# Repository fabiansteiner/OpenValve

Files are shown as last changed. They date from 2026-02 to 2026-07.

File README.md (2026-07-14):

<div align="center">

# OpenValve

<a href="https://open-valve.com/">Get OpenValve</a> | <a href="documents/Construction.md">Build OpenValve</a> | <a href="https://docs.open-valve.com">Documentation</a> | <a href="https://discord.gg/JMEDK97xuT">Join Discord</a>

</div>

## Introduction

OpenValve is an **open-source, 3D-printable irrigation controller**. It waters plants based on **actual soil moisture**, works with **gravity-fed systems**, and runs on a **9V block battery for about 3 months**.

OpenValve First Impressions

OpenValve was built for irrigation. But underneath the soil moisture sensor and irrigation firmware is an open-source pinch valve that you can build other things around.

> [!NOTE]
> **Built for irrigation. Open to other ideas.**
> Add your own sensor, write your own firmware, or connect OpenValve to another system. [Explore OpenValve as a valve platform →](documents/OV-as-platform.md)

## Applications
OpenValve was designed for **balconies, garden beds, small greenhouses, and other small-to-medium irrigation setups**. It has been deployed in multiple real-world locations. Both gravity-fed and faucet-fed (`≤ 4 bar`) setups were successfully tested over full summer seasons.

OpenValve in multiple locations

## ✨ Key Features

### 🚰 3D-Printable Pinch Valve

- bistable (no power needed to hold the open/closed position)
- reliably actuates **down to 0 bar**, making it **perfect for gravity-fed setups**
- requires **no minimum flow**
- tolerates **imperfect or particle-rich water**  
- **8 mm inner flow path** (Cv ≈ 2)  
- Max. pressure: **4 bar** (60 psi)  

Open Valve First Impressions

### 🌧️ Sensor-Based Irrigation

OpenValve does not water on a fixed timer. Instead, it uses a **soil moisture sensor** to decide when watering is needed.

#### How it works:

1. OpenValve regularly measures the soil moisture.
2. If the soil is drier than the threshold you set, the valve opens.
3. Water flows until the sensor detects that moisture is increasing.
4. The valve then either closes immedetiately or stays open for longer, based on the extra watering time you set.
5. OpenValve stops watering and returns to the regular soil moisture measurement.

This allows the watering frequency to adapt to the actual conditions around the plant instead of following a fixed schedule:

When the soil dries out faster, for example during hot weather or periods of increased plant demand, OpenValve waters more often. When the soil stays moist for longer, for example during cooler weather, after rainfall, or after a previous watering cycle, OpenValve waters less often.

For a more detailed explanation of the watering logic, see the ["How OpenValve works" section in the documentation.](https://docs.open-valve.com/category/how-openvalve-works) 

How OpenValve waters

### 🔗 Standard Hose & Pipe Connections

OpenValve has a standard **½″ male BSPP thread on both ends**. This thread size is common in irrigation and plumbing systems in Europe, the UK, Australia, and many other regions.

Any fitting, adapter, or component with a compatible **½″ female BSPP thread** can be connected directly to OpenValve, for example:

* compression fittings
* hose connectors
* thread adapters, such as ½″ to ¾″
* quick-connect fittings
* adapters for different hose sizes

This makes OpenValve flexible enough for setups ranging from a small balcony drip line to a greenhouse irrigation system.

For more details about installing OpenValve, see the [installation section in the documentation](https://docs.open-valve.com/installation/overview).

### 🛠️ Fully Repairable & Modifiable

OpenValve is designed to be repaired, modified, and reused.

* the 3D-printed parts can be reprinted or modified
* the silicone hose (pinch valve sleeve) can be replaced when it wears out
* the firmware can be changed for different behaviours
* the hardware and firmware allow easy integration of different sensors
* the valve can alternatively be powered from an external 5 V, 1 A supply

OpenValve was designed for irrigation, but can also be used for other projects. [Explore OpenValve as a valve platform →](documents/OV-as-platform.md)

## 💡 User Interface

OpenValve’s user interface (UI) is intentionally minimal:

- **1 button**
- **2 LEDs**: one blue LED and one bi-color LED that can show green, red, or orange

Because the device is designed to run autonomously, the UI focuses on simple, essential interactions:

- **Short and long button presses** for menu navigation and configuration  
- **LED patterns** to indicate status, watering activity, sensor readings, and possible errors

To make this easy to understand, every UI state is documented and can be explored interactively:

👉 **Interactive Manual:**  https://ui.open-valve.com/

This web-based “digital twin” mimics the behaviour of the real device - showing the same LED patterns and button interactions, along with explanations for each state.  

For a complete explanation of the button actions, LED blink patterns, and UI states, see the [User Interface documentation](https://docs.open-valve.com/category/user-interface).

## 🤝 Contributing

Contributions are welcome!  
If you’d like to help improve the firmware, CAD files, documentation, or electronics, feel free to open an issue or submit a pull request.

You can also [join the project Discord](https://discord.gg/JMEDK97xuT) to discuss ideas, ask questions, or share feedback.

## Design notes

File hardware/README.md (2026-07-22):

# Bill of Materials (BOM)

In addition to the [PCB](./pcb) and [3D-printed parts](./3D-models), the following components are required to build one OpenValve.

> [!NOTE]
> The product links below are examples, not endorsements. Availability may change, and equivalent parts can be used if their dimensions, materials, and specifications match.

## Enclosure, sealing, and ventilation

| Component | Quantity | Example product |
| --- | ---: | --- |
| M12 cable gland | 1 | [TE Connectivity 1SNG601011R0000 — DigiKey](https://www.digikey.at/en/products/detail/te-connectivity-entrelec/1SNG601011R0000/19203103) |
| Gasket for M12 cable gland | 1 | [TE Connectivity ENBR-WG-M12-BL-A — DigiKey](https://www.digikey.at/en/products/detail/te-connectivity-entrelec/ENBR-WG-M12-BL-A/16686555) |
| Gasket for fitting | 2 | [EPDM flat gasket — PVC-Welt](https://www.pvc-welt.de/EPDM-Flachdichtung-Shore-55-fuer-Aussengewinde-und-Tankdurchfuehrung) |
| Silica gel bag, 10 g | 1 | [Example — Amazon](https://www.amazon.de/dp/B0CTGPC5VB) |
| M12 hydrophobic vent | 1 | [Amphenol LTW VENT-PS1NGY-N8001 — DigiKey](https://www.digikey.at/en/products/detail/amphenol-ltw/VENT-PS1NGY-N8001/7898282) |
| O-ring, 58 mm OD × 2 mm, NBR 70 | 1 | [Example — AliExpress](https://de.aliexpress.com/item/4000867504808.html) |
| O-ring, 30 mm ID × 1.5 mm, NBR 70 | 1 | [Example — Persicaner](https://www.persicaner.at/produkt/nbr-70-o-ring-30-00x1-50o/) |

## Fasteners and mechanical hardware

| Component | Quantity | Example product |
| --- | ---: | --- |
| M3 × 6 mm button-head socket screw, A2 stainless steel | 4 | [ISO 7380-1 screw — Schraubenking](https://www.schraubenking.at/M3-x-6mm-Linsenflachkopfschraube-ISK-ISO7380-1-Edelstahl-A2-P004587) |
| M3 × 10 mm button-head socket screw, A2 stainless steel | 4 | [ISO 7380-1 screw — Schraubenking](https://www.schraubenking.at/M3-x-10mm-Linsenflachkopfschraube-ISK-ISO7380-1-Edelstahl-A2-P002586) |
| M4 × 10 mm button-head socket screw, A2 stainless steel | 3 | [ISO 7380-1 screw — Schraubenking](https://www.schraubenking.at/M4-x-10mm-Linsenflachkopfschraube-ISK-ISO7380-1-Edelstahl-A2-P002759) |
| M4 × 8 mm button-head socket screw, A2 stainless steel | 1 | [ISO 7380-1 screw — Schraubenking](https://www.schraubenking.at/M4-x-8mm-Linsenflachkopfschraube-ISK-ISO7380-1-Edelstahl-A2-P004441) |
| M4 thin square nut, DIN 562, A2 stainless steel | 1 | [Square nut — Schraubenking](https://www.schraubenking.at/M4-Vierkantmuttern-niedrig-DIN562-Edelstahl-A2-P003727) |
| M4 × 6.35 mm threaded insert | 3 | [Threaded insert set — 3DJake](https://www.3djake.at/3djake/gewindeeinsaetze-50er-set?sai=9420) |
| M3 × 5.7 mm threaded insert | 2 | [Threaded insert set — 3DJake](https://www.3djake.at/3djake/gewindeeinsaetze-50er-set?sai=9420) |
| 3 mm × 10 mm cylindrical pin, A1 / 1.4305 stainless steel | 2 | [DIN 7 cylindrical pin — Schraubenhimmel](https://www.schraubenhimmel.de/schrauben/ohne-kopf/zylinderstifte/ungehaertete-ausfuehrung/33260/din-7-edelstahl-a1-1.4305-3x10-zylinderstift-toleranz-m6) |

## Electronics and actuation

| Component | Quantity | Example product |
| --- | ---: | --- |
| 9 V battery clip cable, 15 cm | 1 | [Example — AliExpress](https://de.aliexpress.com/item/1005009963920324.html) |
| Soil moisture sensor | 1 | [SoilWatch 10 — Pino-Tech](https://pino-tech.eu/product/soilwatch-10/) |
| JGA25-370 DC gear motor, 6 V, 10 RPM | 1 | [Example — AliExpress](https://de.aliexpress.com/item/32987942205.html) |

## Valve tubing and assembly materials

| Component | Quantity | Example product |
| --- | ---: | --- |
| Silicone hose, 94 mm length, 60 Shore A | 1 | [8 × 12 mm silicone hose — Persicaner](https://www.persicaner.at/produkt/silikonschlauch-8x12o-transluzent) |
| Silicone adhesive | 1 | [Example — Amazon](https://amzn.eu/d/0cmCepki) |
| Silicone grease | 1 | [Example — Amazon](https://www.amazon.de/dp/B07BFHRT48) |

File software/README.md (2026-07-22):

# 🧠 Firmware

The firmware can be opened, modified, and built using [Microchip Studio](https://www.microchip.com/en-us/tools-resources/develop/microchip-studio).

## 🔌 Flashing Firmware

### UPDI Programmers

OpenValve uses **UPDI (Unified Program and Debug Interface)**.  
To flash firmware, you’ll need a **UPDI programmer**.

You have two options:

#### 1. Make your own programmer:

If you have an **Arudino Uno or Arduino Nano** or any other MCU Board based on the ATMEGA328P lying around you can quite easily use those as a UPDI programmer. The only additional hardware components you need are:
Any capacitor of 1uF or more, and a few jumper wires. 

If you have those components, use the following video as a reference to prepare your programmer:

👉 https://www.youtube.com/watch?v=AL9vK_xMt4E

#### 2. Buy a ready-made programmer
The **NanoUPDI** for example is an inexpensive ready-to-use option:

- GitHub: https://github.com/umbertoragone/nanoupdi  
- Available on:
  - https://lectronz.com/  
  - https://www.tindie.com/  

There are also many other inexpensive UPDI programmers available. When buying one make sure there is the option to set the power output of the programmer to 3.3V.

### How to flash new firmware

The easiest way to flash new firmware without installing Microchip Studio is by using [AVRDUDESS](https://github.com/ZakKemble/AVRDUDESS):

Get the newest firmware from the latest release. Connect OpenValve with your programmer using jumper cables. Make sure the programmers **output power Pin is 3.3V, not 5V**. Then connect the programmer with your PC via USB. 

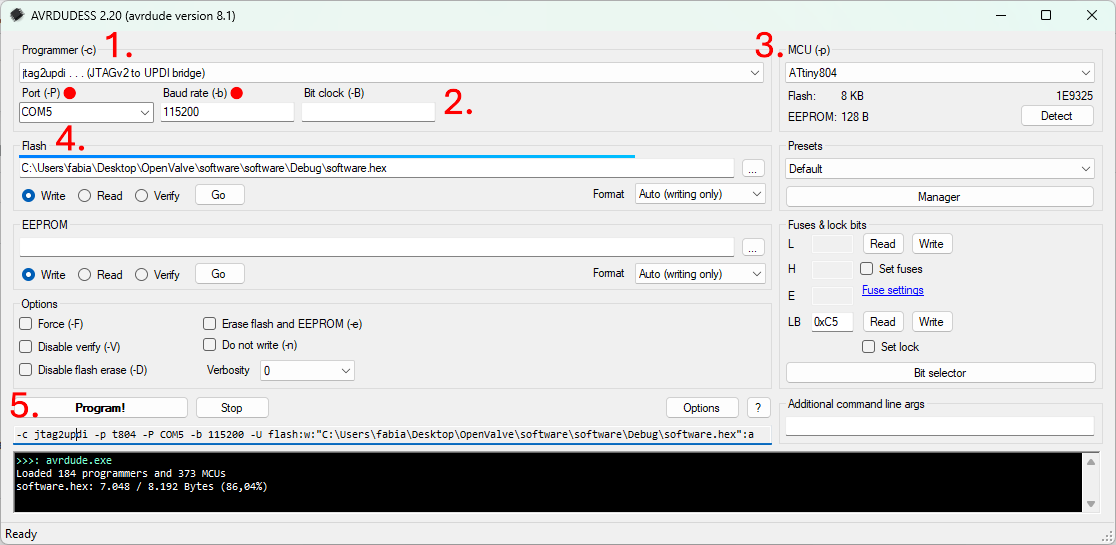
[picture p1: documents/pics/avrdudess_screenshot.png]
avrdudess_settings


Open AVRDUDESS and:

1. Choose the right programmer. jtag2updi for Arduino Uno/Nano based programmer, or SerialUPDI for the NanoUPDI programmer.
2. Choose correct PORT (USB port of your programmer) and Baudrate: 115200
3. Choose correct MCU: ATtiny804
4. Choose firmware binary that should be flashed. (.hex file from the release)
5. Hit Program! 

### ⚠️ Important Warning

The DC motor control logic located in `software/valve.c` is **highly tuned and timing-sensitive**.  
Modifying it without fully understanding the mechanism will **very likely destroy the motor gearbox**.

Proceed with extreme caution when changing anything related to:

- motor control timing  
- stall detection  
- open/close cycle control 
- interrupt behaviour

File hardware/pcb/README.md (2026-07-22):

# 🛠️ Electronics

The PCB was designed using KiCad. OpenValve is based on the ATTINY804 microcontroller.

Schematic, PCB layout and BOM are all open.

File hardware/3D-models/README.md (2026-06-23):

# 🧵 3D Models

All custom plastic parts of OpenValve are **designed and optimized for 3D printing**. No generated support material is required.

This document contains information about the parts and how to produce them yourself.

> [!WARNING]
> Functionality and long-term reliability can only be achieved when all components are printed using the specified materials and slicer parameters.

## ASA Parts

### Tested Filaments

* Fiberlogy ASA
* Prusament ASA

> [!CAUTION]
> Do not use dark filament colors if you intend to use OpenValve outdoors in direct sunlight. Dark colors heat up to higher temperatures under the same conditions and may deform over time.

### Global Slicer Settings

Use these settings for **all ASA parts**, unless stated otherwise in the part-specific section.

| Setting | Value |
| --- | --- |
| Nozzle size | 0.4 mm |
| Layer height | 0.2 mm |
| Perimeters | 4 |
| Infill | 100% |
| Infill pattern | Rectilinear |
| Supports | None |
| Fuzzy skin thickness | 0.2 mm — paint-on only |
| Fuzzy skin point distance | 0.6 mm — paint-on only |

### Print-Yourself ASA Parts

Some ASA parts can either be purchased with the assembly kit or printed by the user:

* `Housing_Up`
* `Housing_Down`
* `Nut_scaled` ×2
* `Guide`
* `MotorMount`
* `Slider`

Ready-to-print profiles for these parts are available on [Printables](https://www.printables.com/model/1564060-openvalve-missing-parts) and [MakerWorld](https://makerworld.com/de/models/2277535-openvalve-missing-parts#profileId-2483396).

Detailed print instructions for these parts can also be found there.

### ASA Parts Included in the Assembly Kit

The following ASA parts are included in the assembly kit by default. They are more difficult to produce reliably, but the settings below are provided for users who still want to print them themselves.

### Part-Specific Slicer Settings

#### Fitting (2 pieces)

The fittings require post-processing by impregnating them with **Dichtol AM Hydro** to handle water pressure. For this reason, they are included in the assembly kit.

| Setting | Value |
| --- | --- |
| Scarf joint placement | Everywhere |
| Enable ironing | Yes |
| Ironing type | Topmost surface only |

#### Battery Lid

The battery lid has an embedded QR code that needs 2 different ASA filaments, a smooth print sheet and very specific slicer settings if printed on a single-extruder system. For that reason it is included in the assembly kit by default.

With a multi-material system, the battery lid should be easy to print. 

If your printer does not have a multi-material system, a dual-extruder system can be simulated to allow a mid-layer material change by tweaking a few slicer settings (PrusaSlicer):

| Path | Setting |
| --- | --- |
| `Printers → General → Extruders` | `2` |
| `Printers → General → Custom G-code → Tool change G-code` | `M600`  |
| `Print Settings → Multiple Extruders → Wipe Tower` | Off |

##### Steps

1. Select two materials (both ASA).

   * Material 1 → QR code (preferably black)
   * Material 2 → rest of the battery lid
2. Assign extruders:

   * Battery lid body → **Material 2**
   * QR code bodies → **Material 1**
3. Slice the model.
4. Inspect the first layer preview.
5. Print if correct

> [!NOTE]
> G-code compatibility warnings can be ignored.

## PC Parts

All PC parts are included in the assembly kit by default.

They are included because they must stay within very narrow tolerances and require highly repeatable printing results. They also require special assembly tools and precise post-processing.

In addition, polycarbonate is not a commonly used 3D-printing material and may not be readily available to every user.

### Tested Filament

* Prusament PC Blend

### Global Slicer Settings

Use these settings for **all PC parts**, unless stated otherwise in the part-specific section.

| Setting | Value |
| --- | --- |
| Layer height | 0.15 mm |
| Perimeters | 4 |
| Infill | 100% |
| Infill pattern | Rectilinear |
| Cooling | Disable the fan for the first layer only |

### Part-Specific Slicer Settings

#### Link2 (2 pieces)

#### Shell (2 pieces)

## Other Parts

### Button

**Tested filament**

* Recreus Filaflex SEBS Black

#### Part-Specific Slicer Settings

| Setting | Value |
| --- | --- |
| Nozzle temperature | 260 °C |
| Layer height | 0.2 mm |
| Perimeters | 4 |
| Infill | 100% |
| Infill pattern | Rectilinear |

### Knob (2 pieces)

**Tested filament**

* Fiberlogy Easy PET-G Pure Transparent

#### Part-Specific Slicer Settings

| Setting | Value  |
| --- | --- |
| Layer height | 0.2 mm |
| Perimeters | 5 |

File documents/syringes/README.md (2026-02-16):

# Syringes

### Silicone Glue

The silicone glue syringe is filled with [Tec7 Rock](https://tec7.com/en-BE/products/mount-seal/rock). Technical and Safety Datasheet can be found on the website. A copy of the safety datasheet is located in the["DS"](DS) folder.

### Silicone Grease
The silicone grease syringe is filled with [weicon silicone grease](https://www.weicon.de/en/silicone-grease-food-safe-lubricating-grease/10050566). Technical and Safety Datasheet can be found on the website. A copy of the safety datasheet is located in the["DS"](DS) folder.

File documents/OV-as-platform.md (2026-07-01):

# OpenValve Beyond Irrigation

OpenValve was originally designed for irrigation. The soil moisture sensor and the firmware turn it into an irrigation controller.

Take those irrigation-specific parts away, and you are left with an **open-source pinch valve**. From there, the project is yours to shape: add your own sensor, write your own firmware, or connect it to another system and use just as a valve.

> [!NOTE]
> **OpenValve comes with one finished application.** What you build around the valve is up to you.

At its core, OpenValve is a bistable pinch valve. It switches quickly, only needs power while moving, and has low internal flow resistance when open. The standard version uses **½-inch BSPP threads** because they are common in irrigation and provide secure connections for pressurised water systems. Not every project needs that, though.

Some projects do not need threaded fittings or higher pressure handling. Instead, they benefit from a clean, uninterrupted flow path. For this, I made an [alternative fitting](../hardware/3D-models/ASA-parts/alternativeParts/) that allow one continuous hose to run straight through OpenValve.

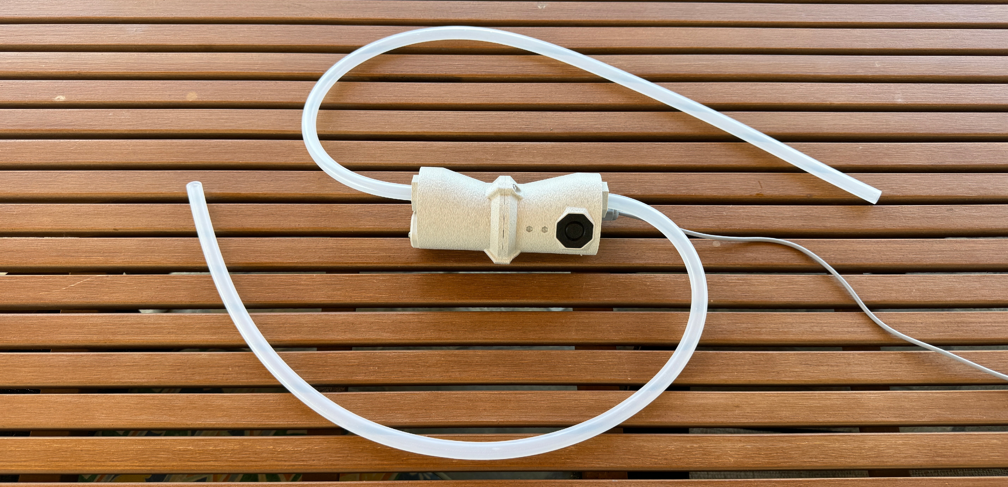
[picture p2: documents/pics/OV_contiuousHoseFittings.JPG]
OpenValve with a continuous hose running through it


The hose can be inserted from the outside without opening the housing. OpenValve pinches the hose from the outside, while the liquid stays inside the hose for the entire path through the valve. The liquid never touches the valve mechanism or housing, similar to a peristaltic pump. The difference is that OpenValve does not pump the liquid. It only opens or closes the hose, while gravity or another external pressure source moves the liquid. Because of that, OpenValve needs only a fraction of the electrical energy that a peristaltic pump would need to move the same amount of liquid, making it generally a good candidate for battery-powered applications.

To give you an idea of where this could become handy, here are a few things I could imagine building with it:

* a gravity-fed cocktail robot, with ingredient bottles above the machine and one valve controlling each ingredient
* a drink dispenser for water, juice, cold brew, syrups, or other liquids
* a small automated refill system for tanks, containers, or reservoirs that refills from an elevated reservoir when a water-level or weight sensor detects that it is low
* a simple timed dosing system for aquarium additives, hydroponic nutrients, fertiliser, or cleaning liquids
* a DIY dispenser for sauces, soap, or other liquids where the product should stay inside a replaceable hose

## Recommended hose for the continuous-hose fittings

OpenValve is designed for hoses with:

* **Inner diameter:** **8 mm**
* **Outer diameter:** **12 mm**
* **Hardness:** **60 Shore A ±10**

The hose hardness is important. A hose that is too hard needs more force to pinch closed, and there is a real risk that it will not fully recover after being pinched. In that case, the hose can stay partially collapsed even when the valve opens, restricting or completely blocking the flow. This is a serious issue and should be considered carefully when choosing a hose.

I tested a range of hose materials and hardnesses. So far, a silicone hose with a **shore hardness of 60A** is the only option that has worked reliably for this design so far.

Because the liquid only touches the inside of the continuous hose, the hose material alone determines which liquids can be transported with it. A certified food-safe silicone hose can for example be used for food-contact applications, as long as the other wetted parts in the final system are also suitable for that use.

## Firmware templates for other projects

The hardware can be used for many different ideas, but the current firmware was built for irrigation. There are no ready-made guides or template firmwares for the examples above yet.

Right now, using OpenValve for a different purpose means adapting the irrigation firmware yourself. That is possible, but it is more work than it should be.

I want to change that by creating small, well-documented template firmwares for practical use cases. These will mostly not be finished and polished firmwares, but simple starting points for projects such as a timed dispenser, a tank refill system or a firmware that just waits for a digital input to open/close the valve.

Have an idea you would actually like to build? [Join the Project Discord](https://discord.gg/JMEDK97xuT) and share it, or write DM. Concrete ideas help me decide which templates and guides to create first.

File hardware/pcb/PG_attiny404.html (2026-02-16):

# C:\Users\fabia\PlantGuardDrive\PCB_Designs\pcb\PG_attiny404.kicad_sch

17.06.2023 08:18:30

Eeschema 7.0.1

Component Count:28

Ref | Qnty | Value | Part | Datasheet | Description | Vendor
C1, C2, C5 | 3 | 1uF | Device:C | ~ | Unpolarized capacitor
C3, C6 | 2 | 100nF | Device:C | ~ | Unpolarized capacitor
C4 | 1 | 10uF | Device:C | ~ | Unpolarized capacitor
J1 | 1 | 0022232041 | dk_Rectangular-Connectors-Headers-Male-Pins:0022232041 | https://www.molex.com/pdm_docs/sd/022232041_sd.pdf | CONN HEADER VERT 4POS 2.54MM
J2, J3, J4, J5, J6, J7, J8 | 7 | Conn_01x01_Male | Connector:Conn_01x01_Male | ~ | Generic connector, single row, 01x01, script generated (kicad-library-utils/schlib/autogen/connector/)
Q1 | 1 | 2N7002 | PG_attiny404-rescue:2N7002-dk_Transistors-FETs-MOSFETs-Single | https://www.onsemi.com/pub/Collateral/NDS7002A-D.PDF
R1, R2 | 2 | 100 Ohm | Device:R | ~ | Resistor
R3 | 1 | 0.5 Ohm | Device:R | ~ | Resistor
R4 | 1 | 665 Ohm | Device:R | ~ | Resistor
R5 | 1 | 200k | Device:R | ~ | Resistor
R6 | 1 | 100k | Device:R | ~ | Resistor
SW1 | 1 | SW_Push | Switch:SW_Push | ~ | Push button switch, generic, two pins
U1 | 1 | ATtiny404-SS | PG_attiny404-rescue:ATtiny404-SS-MCU_Microchip_ATtiny | http://ww1.microchip.com/downloads/en/DeviceDoc/50002687A.pdf
U2 | 1 | AH9246 | project:AH9246 | https://www.diodes.com/assets/Datasheets/AH9246.pdf | Hall Sensor, Package: TO92S
U3 | 1 | XLUGR34M | project:XLUGR34M | https://www.sunledusa.com/products/spec/XLUGR34M.pdf | Red-Green LED with common Cathode
U4 | 1 | ZXCT1009F | Amplifier_Current:ZXCT1009F | https://www.diodes.com/assets/Datasheets/ZXCT1009.pdf | High-Side Current Monitor, SOT-23
U5 | 1 | AP7370-33Y-13 | project:AP7370-33Y-13 | https://www.diodes.com/assets/Datasheets/AP7370.pdf
U6 | 1 | MP6513GJ | project:MP6513GJ | https://www.monolithicpower.com/en/documentview/productdocument/index/version/2/document_type/Datasheet/lang/en/sku/MP6513/document_id/169

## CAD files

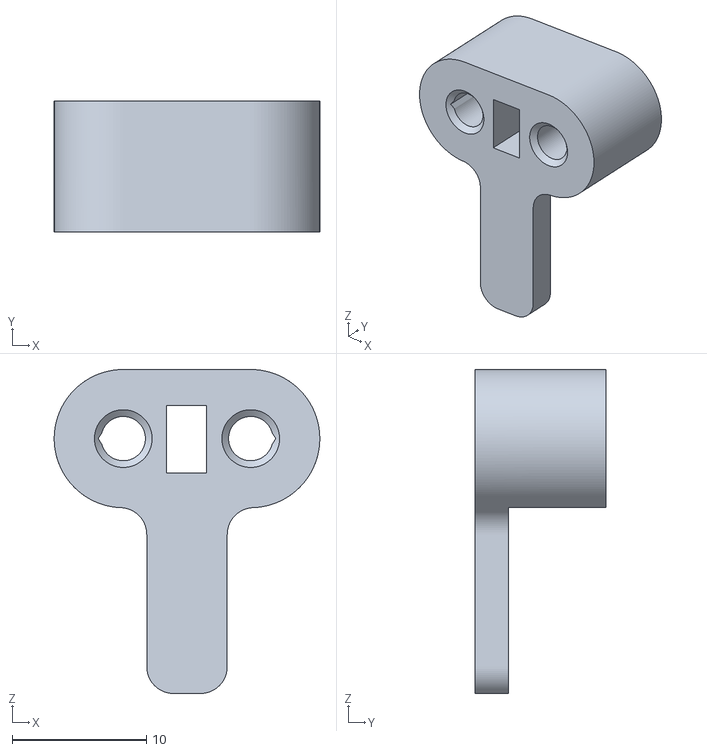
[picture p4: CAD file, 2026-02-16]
hardware/3D-models/Helper Tools/LinkAssemblyGuide.stl
19.8 x 9.80 x 24.2

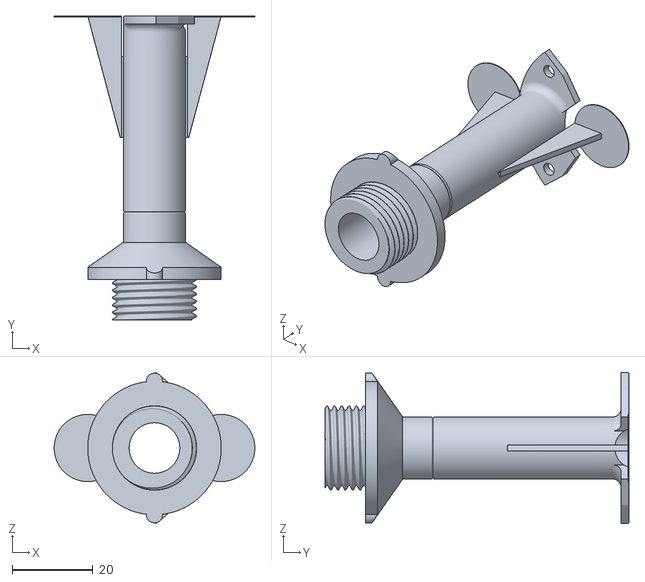
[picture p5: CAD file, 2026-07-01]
hardware/3D-models/ASA-parts/alternativeParts/continuousHoseFitting.stl
49.6 x 75.1 x 37.4

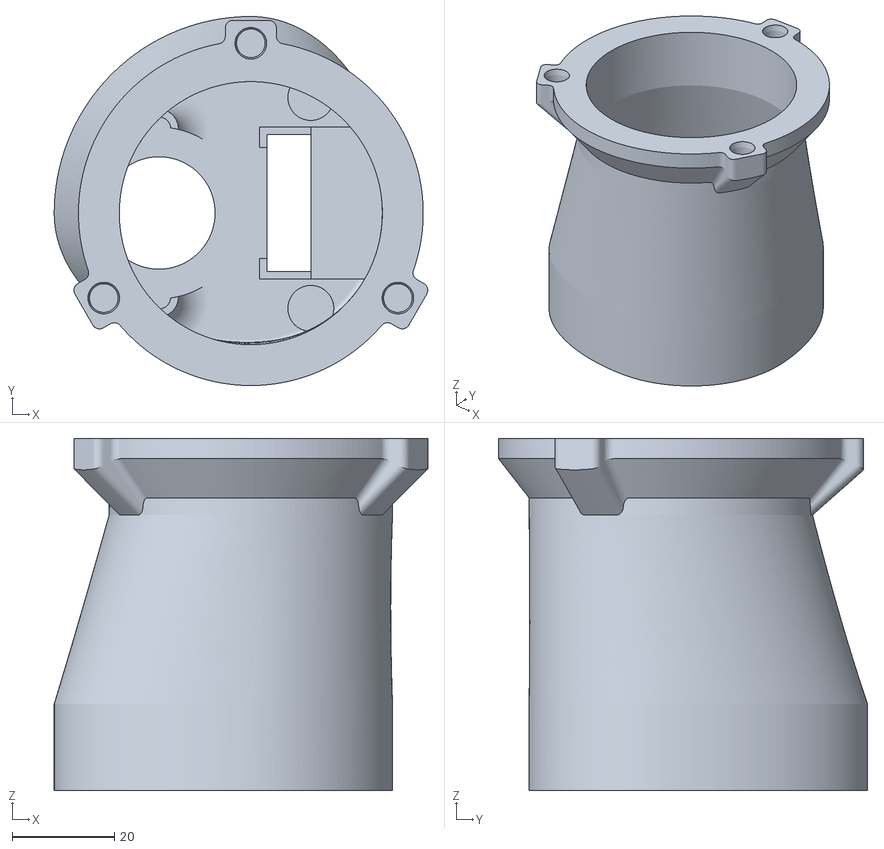
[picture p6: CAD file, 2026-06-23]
hardware/3D-models/ASA-parts/Housing_Up.stl
73.1 x 72.2 x 69.0

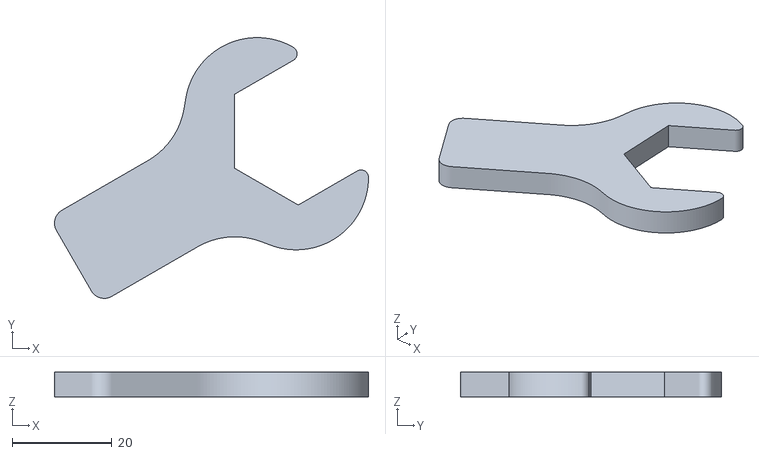
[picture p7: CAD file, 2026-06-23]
hardware/3D-models/Helper Tools/Wrench.stl
63.1 x 52.4 x 5.00

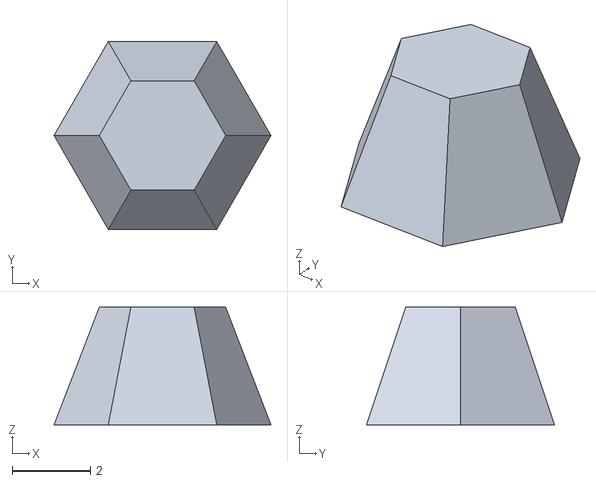
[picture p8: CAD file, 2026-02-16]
hardware/3D-models/Knob.stl
5.53 x 4.79 x 3.00

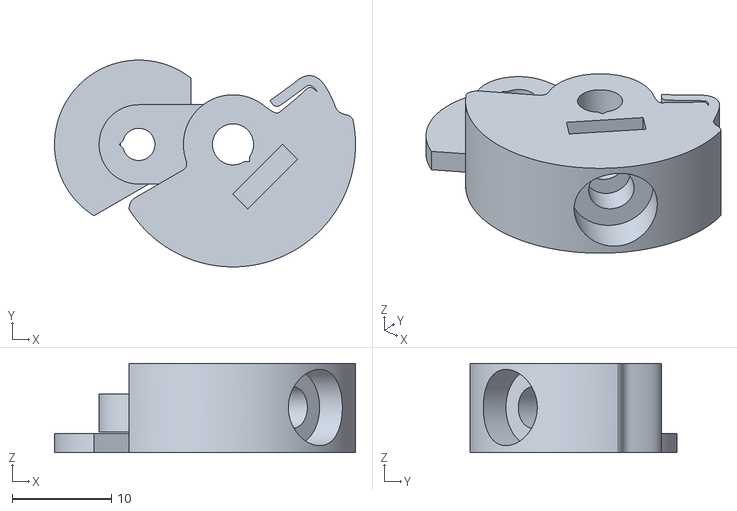
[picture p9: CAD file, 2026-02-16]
hardware/3D-models/PC-parts/Link1.stl
30.3 x 20.8 x 9.00

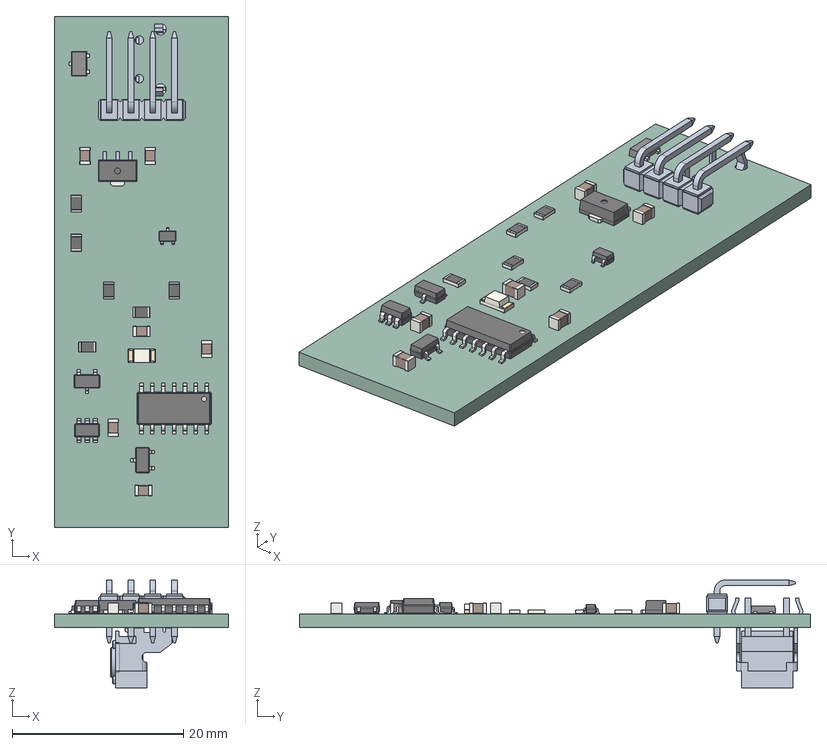
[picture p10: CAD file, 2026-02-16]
hardware/pcb/PG_attiny404.step
20.3 x 59.7 x 12.6 mm
PCB

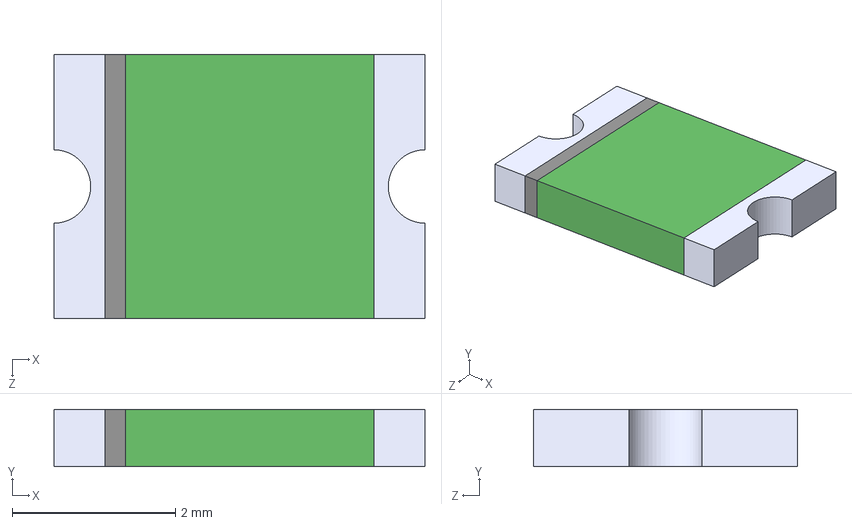
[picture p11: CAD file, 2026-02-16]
hardware/pcb/specific_parts/0ZCG0075FF2C/0ZCG0075FF2C.STEP
4.55 x 0.7 x 3.24 mm

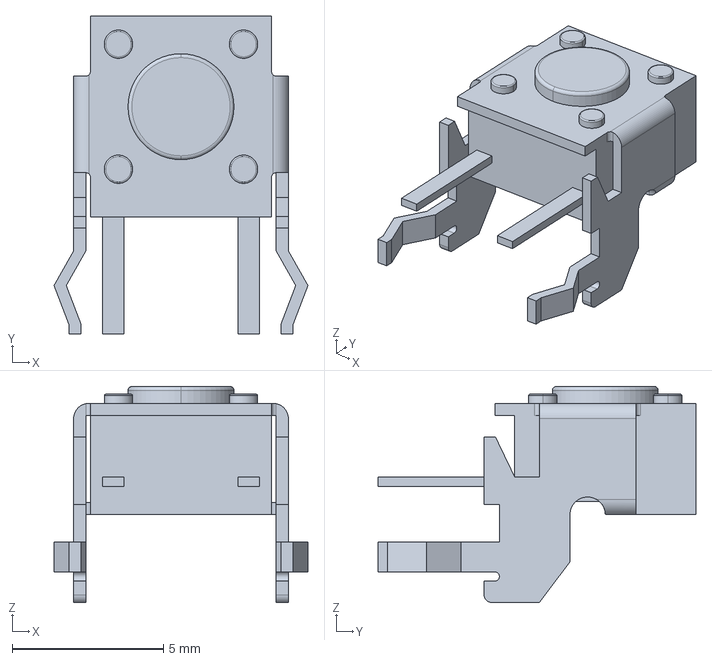
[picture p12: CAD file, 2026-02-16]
hardware/pcb/specific_parts/1825027-2/c-1825027-2-g-3d.stp
8.41 x 10.5 x 7.15 mm

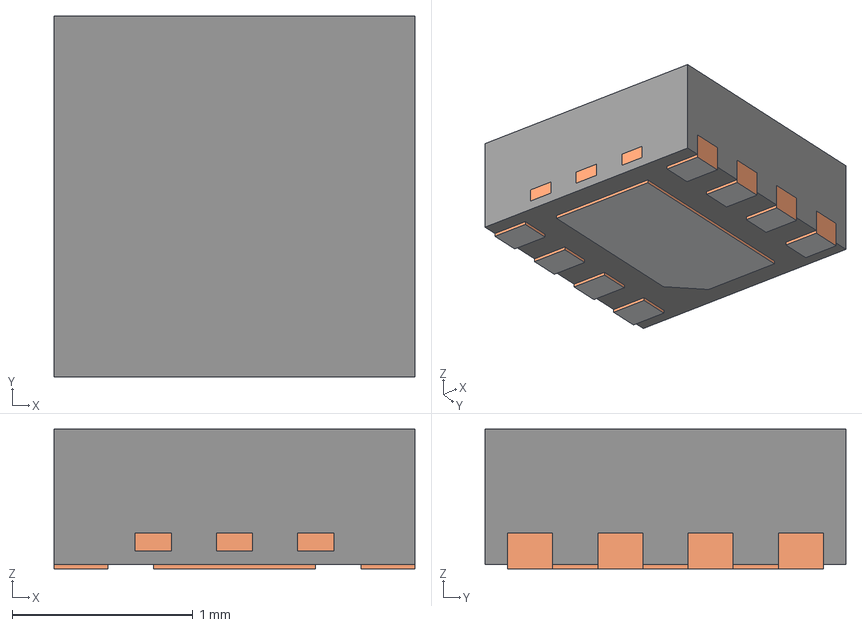
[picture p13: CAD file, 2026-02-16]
hardware/pcb/specific_parts/DRV8837DSGR/DRV8837DSGR.stp
2.00 x 2.00 x 0.775 mm
BODY-SON
FRAME-DSG0008A
PIN1-ID

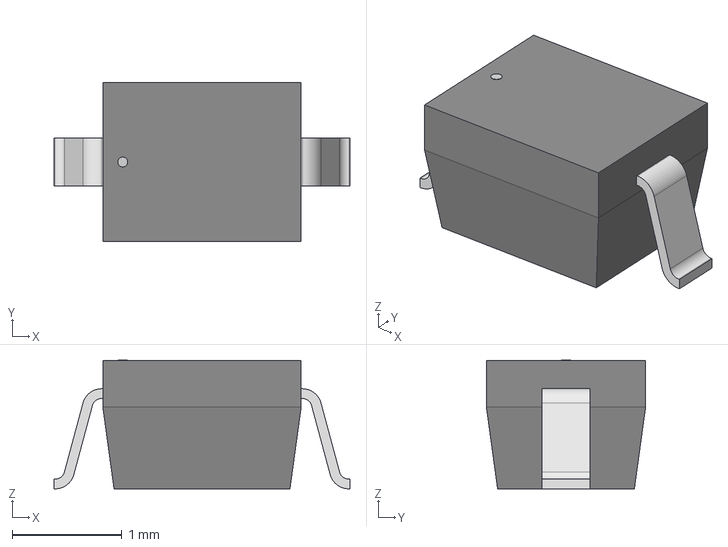
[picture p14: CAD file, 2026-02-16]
hardware/pcb/specific_parts/ESDA041-1JY/CR_041-1JY_STM.step
2.69 x 1.45 x 1.17 mm

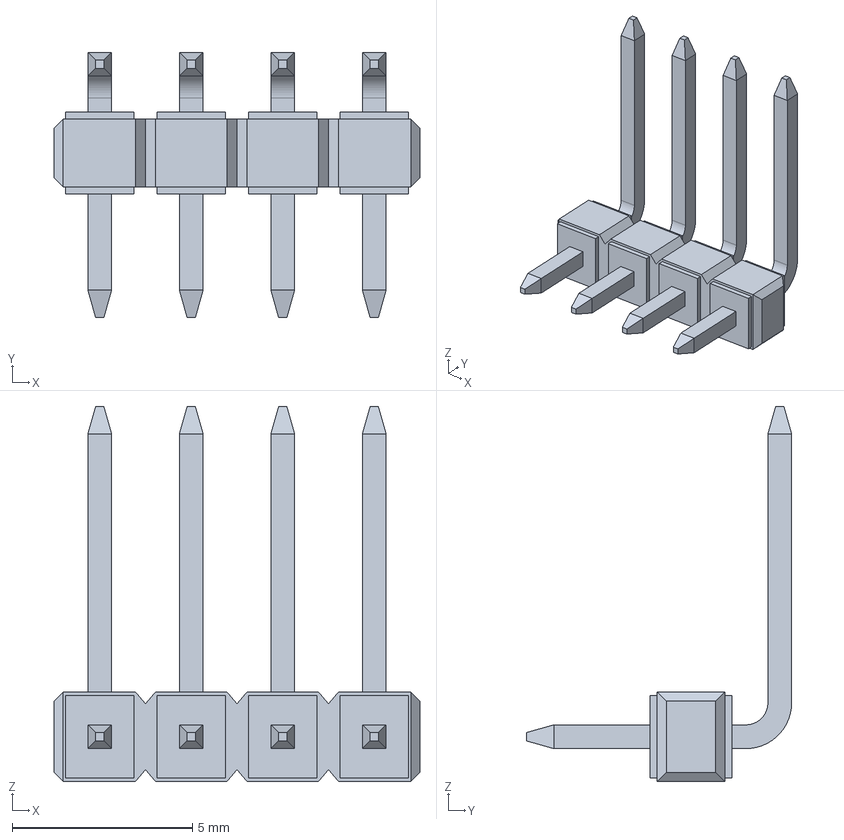
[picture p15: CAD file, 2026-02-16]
hardware/pcb/specific_parts/pinheader.stp
10.2 x 7.37 x 10.4 mm

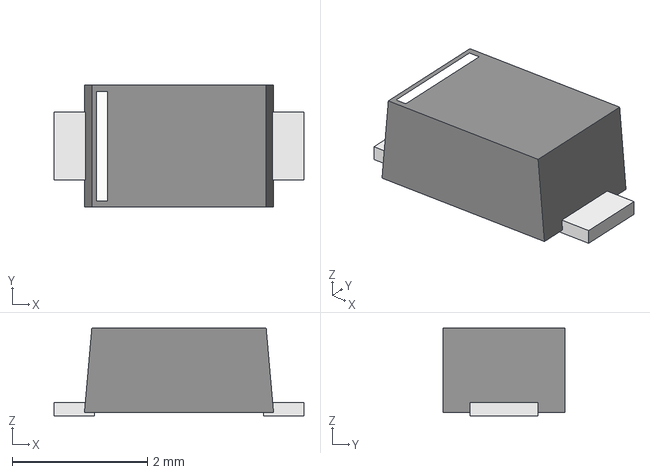
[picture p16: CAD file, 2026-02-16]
hardware/pcb/specific_parts/SMF13A/SMF13A.STEP
3.70 x 1.80 x 1.30 mm

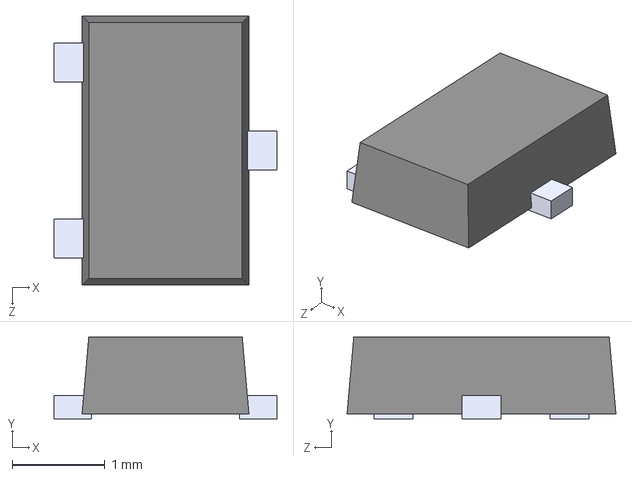
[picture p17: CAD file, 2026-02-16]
hardware/pcb/specific_parts/SSM3J338R_LF/SSM3J338R_LF.step
2.40 x 0.88 x 2.90 mm

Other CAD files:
hardware/3D-models/ASA-parts/Housing_Down.stl
hardware/3D-models/Button.stl
hardware/3D-models/PC-parts/Link2.stl
hardware/3D-models/ASA-parts/Slider.stl
hardware/3D-models/ASA-parts/BatteryLid.3mf
hardware/3D-models/ASA-parts/Guide.stl
hardware/3D-models/ASA-parts/MotorMount.stl
hardware/3D-models/ASA-parts/Nut_scaled.stl
hardware/3D-models/PC-parts/Link3.stl
hardware/3D-models/PC-parts/Shell.stl

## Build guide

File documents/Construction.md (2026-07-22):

## 🔧 How to Build OpenValve

### Assembly Guide

The [Assembly Guide Video](https://youtu.be/af_efyuOWUs) guides you through the build with detailed, step-by-step assembly instructions.

### To build your own OpenValve, you need:

- [The OpenValve Assembly Kit and a soil moisture sensor](https://lectronz.com/products/openvalve-assembly-kit-v1-0)
- An enclosed 3D printer capable of printing ASA without warping*
- ASA filament*
- 1 × 9 V alkaline battery
- Basic soldering equipment
- Basic hand tools, such as Allen keys and pliers

*Optionally, all missing 3D-printed parts can be purchased with the Assembly Kit. In that case, no 3D printer or filament is required to build OpenValve.

### Building OpenValve from Scratch

As an alternative to using the Assembly Kit, you can source all components yourself and build OpenValve completely from scratch. All required resources are available in this repository.

The hardware files—including the [PCB](./../hardware/pcb/), [3D models](./../hardware/3D-models/), and [BOM](./../hardware/)—as well as the [firmware](./../software/) are all open source.

> [!WARNING]
> If you are considering self-sourcing OpenValve, please read this carefully. This is not intended as an advertisement for the Assembly Kit, but as practical advice based on real and frustrating experiences.
>
> The 3D-printed parts included with the Assembly Kit require very tight tolerances and very high print quality to work properly. Printing these parts yourself is likely to result in components that fall outside the required specifications, even when they look correct. These small deviations often cause poor fits, creating a substantial risk of water entering the housing and damaging the electronics.
>
> For this reason, the critical 3D-printed valve components that require precise manufacturing are included in the Assembly Kit by default.

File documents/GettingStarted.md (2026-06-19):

# Getting Started

The getting started guide has moved to the OpenValve documentation website:

[OpenValve Documentation](https://docs.open-valve.com)

Recommended starting points:

* [How OpenValve works](https://docs.open-valve.com/category/how-openvalve-works)
* [User Interface](https://docs.open-valve.com/category/user-interface)
* [Installation](https://docs.open-valve.com/installation/overview)
* [First Setup](https://docs.open-valve.com/first-setup)

The documentation website is now the main place for setup instructions, installation guides, and usage information.

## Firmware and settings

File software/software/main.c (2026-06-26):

/*
 * software.c
 *
 * Created: 15.10.2022 16:24:59
 * Author : Gus
 */ 

#define F_CPU 3333333
#define MULTIPLICATOR_TIME_LIMIT 7200 // 640 oder 32 Test - 7200 = 2 Stunden Prod

#include "common.h"
#include "ADC.h"
#include "LEDs.h"
#include "EEPROM.h"
#include <avr/interrupt.h>
#include <avr/sleep.h>
#include <util/atomic.h>

typedef enum {
	ACTIVE = 1,
	PERIODICWAKEUP = 2,
	SLEEP = 3,
	OFF = 4
}  mainStates;


volatile mainStates mState = SLEEP;
volatile uint8_t wakeUpCycles = 1;
volatile uint8_t sleepCounter = 0;
volatile uint8_t manualIrrigation = 0;
volatile uint8_t buttonSensingOn = 0;		//Used to check if the button is being pressed or not, if 0 button is being pressed, if 1 button is currently not pressed, but only goes 0 when button is pressed in state SLEEP or OFF

volatile uint16_t irrigationTimeCounter = 0;
volatile uint8_t currentSleepTime = 4;
uint16_t miliSecCounter = 0;
uint8_t executeMultiplicator = 0;




#define PB0_HIGH (PORTB.IN & PIN0_bm)
#define PB0_INTERRUPT PORTB.INTFLAGS & PIN0_bm
#define PB0_CLEAR_INTERRUPT_FLAG PORTB.INTFLAGS &= PIN0_bm

void enablePITInterrupt(){
	RTC.PITINTCTRL |= (1<<0);
}
void disablePITInterrupt(){
	RTC.PITINTCTRL &= ~(1<<0);
}

void enablePORTBInterrupt(){
	PORTB.PIN0CTRL |=  PORT_ISC_BOTHEDGES_gc;
}

void disablePORTBInterrupt(){
	PORTB.PIN0CTRL &=  ~PORT_ISC_BOTHEDGES_gc;
}


ISR(RTC_PIT_vect)
{
	
	if(mState != ACTIVE){
		sleepCounter++;
		if(sleepCounter >= wakeUpCycles){
			disablePORTBInterrupt();
			mState = PERIODICWAKEUP;
			
		}
		
	}
	RTC.PITINTFLAGS = RTC_PI_bm;
	PB0_CLEAR_INTERRUPT_FLAG;
	
}


ISR(PORTB_PORT_vect)
{
	
	if(PB0_INTERRUPT)
	{
		if(PB0_HIGH){
			if(mState != ACTIVE && mState != PERIODICWAKEUP){
				buttonSensingOn = 0;
				disablePITInterrupt();
				
				if(mState == SLEEP){

					mState = ACTIVE;
					irrigationTimeCounter = 0;

					if(getValveError() == NO_ERROR){
						uiState = SHOWBATTERY;
						changeLEDAnimation(FROM_SHOWNOTHING_TO_SHOWBATTERY);
					}else{
						uiState = ERRORSTATE;
						changeLEDAnimation(SHOW_ERROR);
					}

					
				}
				
			}
		}else{
			buttonSensingOn = 1;
		}
		PB0_CLEAR_INTERRUPT_FLAG;
		RTC.PITINTFLAGS = RTC_PI_bm;
	}
	
}

void initSleep(void)
{
	SLPCTRL.CTRLA |= SLPCTRL_SMODE_PDOWN_gc;
	SLPCTRL.CTRLA |= SLPCTRL_SEN_bm;
	
	PORTB.DIR &= ~ PIN0_bm;												//Set as input
	PORTB.PIN0CTRL |= PORT_PULLUPEN_bm | PORT_ISC_BOTHEDGES_gc;			//Enable Pull-UP & enable interrupt on falling edge

	//configure RTC PIT
	RTC.CLKSEL |= RTC_CLKSEL_INT1K_gc;					//Use 1024Hz clock for RTC
	RTC.PITINTCTRL |= (1<<0);							//Enable Periodic Interrupt

	//while((RTC.PITSTATUS & (1<<0)) != 0);				//Wait until a possibly ongoing synchronization of RTC.PITCTRLA register is done.
	//RTC.PITCTRLA |= RTC_PRESCALER_DIV2048_gc | (1<<0);	//Set Periodic Interrupt Cycle to 1024, interrupt should happen now every second.


}


void changePIT(uint8_t prescaler, uint8_t cycles){
	while((RTC.PITSTATUS & (1<<0)) != 0);
	RTC.PITCTRLA = prescaler | (1<<0);
	while((RTC.PITSTATUS & (1<<0)) != 0);
	wakeUpCycles = cycles;
}

void changePITInterval(){
	if(getValveState() == OPEN){
		if(irrigationTimeCounter <= 180){ //24 Test - 180 Prod
			changePIT(RTC_PRESCALER_DIV1024_gc, 2); currentSleepTime = 4;	//4 seconds important comment: changePIT(RTC_PRESCALER_DIV2048_gc, 1); does not work, because after the valve goes into sleep mode i cannot wakup by button press until the next periodic wakeup, this only occurs with this specific setting
			//changePIT(RTC_PRESCALER_DIV128_gc, 2); currentSleepTime = 4;
		}else if (irrigationTimeCounter <= 596){ //104 Test - 592 Prod
			changePIT(RTC_PRESCALER_DIV8192_gc, 1); currentSleepTime = 16;	//16 seconds
			//changePIT(RTC_PRESCALER_DIV1024_gc, 1); currentSleepTime = 16;
		}else{
			changePIT(RTC_PRESCALER_DIV16384_gc, 2); currentSleepTime = 64;	//~1 minute
			//changePIT(RTC_PRESCALER_DIV2048_gc, 2); currentSleepTime = 64;
		}


	}else if(getValveState() == CLOSED){
		//changePIT(RTC_PRESCALER_DIV1024_gc, 8); //shorter timespan for debugging
		changePIT(RTC_PRESCALER_DIV16384_gc, 60); //30min prod
	
	}
	
}

uint8_t switchOFF(){

	closeValve();

	if (getValveError() != NO_ERROR) {
		return 0;		// Error: caller must fall through to normal error handling
	}

	directlyTriggerAnimation(A_TRANSITIONING_SHUTDOWN);
	disablePITInterrupt();
	PORTB_OUTCLR = (1<<BLUE_LED);
	manualIrrigation = 0;
	while(getLEDAnimation() != NO_ANIMATION);
	mState = OFF;
	sleep_mode();

    return 1; //sleep_mode() returns here after wake-up. mState is still OFF here. Caller must skip the remainder of the old ACTIVE-loop iteration. 
}


int main(void)
{

	sei();
	initLEDs();

	//if UI button is being pressed on power up enter motor positioning mode
	if((PORTB_IN & (1<<PIN_MAGNETSWITCH))!=0){
		_delay_ms(5);								// Debouncing
		directlyTriggerAnimation(A_MOTORPOSITIONING);
		uint8_t pressCounter = 0;
		while((PORTB_IN & (1<<PIN_MAGNETSWITCH))!=0){
			_delay_ms(100);
			pressCounter++;
			if(pressCounter >= 100)
				break;
		}	// Wait for button release
		if(pressCounter<100){
			motorPositioningMode();
		}else{
			valveCylces = 0;
			writeValveCycles(valveCylces);
			directlyTriggerAnimation(A_TRANSITIONING_RESETCYCLES);
			while(getLEDAnimation() == A_TRANSITIONING_RESETCYCLES);
		}
		
	}

	
	
	initSleep();
	//uart_init(9600);
	initUI();
	initADC();
	initializeValve();
	changePITInterval();

	
	_delay_ms(100);			//Let setting settle in
	uint16_t SM;
	uint8_t motorStateChanged = 0;

	
	
	sleep_mode();
	
    while (1) 
    {
		if (mState == ACTIVE || mState == PERIODICWAKEUP){
			
			//set blue led if valve is open
			if(manualIrrigation == 0){
				if(getValveState() == OPEN) PORTB_OUTSET = (1<<BLUE_LED);
				else PORTB_OUTCLR = (1<<BLUE_LED);
			}
			
			if(getValveError()==NO_ERROR){

			
				//Get new battery measurment and set warning state if too low
				if(valveCylces >= 1450 || getDriveVoltageLowCount() >= DRIVE_VOLTAGE_LOW_TRIGGER || ADC_0_readBatteryVoltage() <= BATTERY_LEVEL_VERYLOW_ADC)
					warningState = WARNING;
				else
					warningState = NO_WARNING;

			
				if(mState == ACTIVE){
				
					pressType button_press = NONE;
					
					
					if(buttonSensingOn){
						button_press = senseMagneticSwitch();
					}
					
				
					state_change changeOfState = changeUIState(button_press);
				
					//Do not count timeout when in manual irrigation mode
					if(getUIState()!=MANUALIRRIGATION){
						state_change timeOutStateChange = countUITimeOut();
						if(timeOutStateChange != NO_CHANGE){changeOfState = timeOutStateChange;}
					}

					changeLEDAnimation(changeOfState);
					cycleLEDAnimation();
				
					if(changeOfState == FROM_SHOWSOILMOISTURE_TO_MANUALIRRIGATION){
						manualIrrigation = 1;
						openValve();
					}else if (changeOfState == FROM_MANUALIRRIGATION_TO_SHOWSOILMOISTURE){
						manualIrrigation = 0;
						closeValve();
						irrigationTimeCounter=0;
						miliSecCounter=0;
					}
				
					if (changeOfState == UI_SHUTDOWN) {
						if (switchOFF()) {continue;}
					}

				}else if(mState == PERIODICWAKEUP){
					if(getValveState() == CLOSED){
						//If warning is present turn on warning sign at periodic wakeup when valve is closed
						if(warningState == WARNING && getValveState() == CLOSED){
							PORTA.OUTSET = (1<<PIN_REDLED);
							PORTB.OUTSET = (1<<PIN_GREENLED);
						}
					}
					
				}

				//If manual irrigation off = normal operation = Take Soil Moisuture Measurement and Open/Close
				if(manualIrrigation == 0 && executeMultiplicator == 0){

					PORTA_OUTSET = (1<<PIN_SOILSENSORON);	//Turn on soil mositure sensor, takes around 5ms to get stable measurement
					_delay_ms(MAINLOOP_DELAY/2);
					
					//turn off warning sign when periodic wakeup and there is a warning present
					if(mState == PERIODICWAKEUP && warningState == WARNING){
						PORTA.OUTCLR = (1<<PIN_REDLED);
						PORTB.OUTCLR = (1<<PIN_GREENLED);
					}

					_delay_ms(MAINLOOP_DELAY/2);
					SM = ADC_0_readSoilMoisture();
					PORTA_OUTCLR = (1<<PIN_SOILSENSORON);	//Turn off soil mositure sensor

					
				
					if(SM >= getCurrentThresholds().thresholdClose){
						if(getValveState() == OPEN){
							if(mState == ACTIVE || getCurrentMultiplicator() == 1){
								closeValve();
								motorStateChanged = 1;
								irrigationTimeCounter = 0;
								executeMultiplicator = 0;
							}else{ //Calculate irrigation time 
								
								uint16_t newIrrigationTimeCounter = irrigationTimeCounter * (0.5f * (getCurrentMultiplicator()-1));
								
								if(irrigationTimeCounter > MULTIPLICATOR_TIME_LIMIT){ //If irrigation time already bigger than 2 hours then just close
									//This case is now handled in later logic, where error is thrown for wrong sensor placement
									//closeValve();
									//irrigationTimeCounter = 0;
								}else if ((irrigationTimeCounter + newIrrigationTimeCounter) > MULTIPLICATOR_TIME_LIMIT){	//If calculated irrigation would be bigger than 2 hours then set time so it is maximum 2 hours.
									irrigationTimeCounter = (MULTIPLICATOR_TIME_LIMIT - irrigationTimeCounter)-4;	//-4 for accuracy
									executeMultiplicator = 1;
								}else{			//Otherwise just use the calculated time using the set multiplicator
									irrigationTimeCounter = newIrrigationTimeCounter;
									executeMultiplicator = 1;
								}
									
								
								
							}
							
						}
					}else if (SM <= getCurrentThresholds().tresholdOpen){
						if(getValveState() == CLOSED){
							openValve();
							motorStateChanged = 1;
						}
					}
				//If manual irrigation on = just wait, measuring is not necessary
				}else if(manualIrrigation == 1 && executeMultiplicator == 0){
					_delay_ms(MAINLOOP_DELAY);
					miliSecCounter += MAINLOOP_DELAY;
					if(miliSecCounter >=1000){
						irrigationTimeCounter++;
						miliSecCounter=0;
						
						if(irrigationTimeCounter >= 819){	//900=15min timeout - 819 because of course time for other compute is needed besides the mainloop delay
							//Simulate button press
							changeUIState(SHORT);
							
							manualIrrigation = 0;
							closeValve();
							irrigationTimeCounter=0;
							miliSecCounter=0;
							
							changeLEDAnimation(FROM_MANUALIRRIGATION_TO_SHOWSOILMOISTURE);
							cycleLEDAnimation();
						}
					}
					
					
					
				}else if (executeMultiplicator == 1){
					// Close, when multiplicator time was executed or state changes to active
					if(irrigationTimeCounter < 5 || mState == ACTIVE){
						closeValve();
						executeMultiplicator = 0;
						irrigationTimeCounter = 0;
					}
					
				}


				//If error occured after driving the motor, change to error state
				if(getValveError() != NO_ERROR){
					//PIT interval to 4 sec
					changePIT(RTC_PRESCALER_DIV2048_gc, 1);
					uiState = ERRORSTATE;
					if(mState == ACTIVE) changeLEDAnimation(SHOW_ERROR);
					
				}else if (getValveError() == NO_ERROR){
					//If no error occured process normal operation
					if(mState == PERIODICWAKEUP){
						changePITInterval();
						if (getValveState() == OPEN && executeMultiplicator == 0) {
							if (irrigationTimeCounter < (MULTIPLICATOR_TIME_LIMIT - currentSleepTime)){
								irrigationTimeCounter += currentSleepTime;
							}else{
								//Valve open for longer than 2 hours -> Sensor Placement Wrong or Water Not Flowing
								closeValve();
								if(getValveError() == NO_ERROR){
									setValveError(WRONG_SENSOR_PLACEMENT);
								}
								irrigationTimeCounter = 0;
								changePIT(RTC_PRESCALER_DIV2048_gc, 1); //PIT interval to 4 sec
								uiState = ERRORSTATE;

							}
								

						}else if (executeMultiplicator == 1 && irrigationTimeCounter >= currentSleepTime){
							irrigationTimeCounter -= currentSleepTime;
						}
						
						
						sleepCounter = 0;
						motorStateChanged = 0;
						mState = SLEEP;
						PORTB_OUTCLR = (1<<BLUE_LED);
						enablePORTBInterrupt();
						sleep_mode();
				
					}else if(mState == ACTIVE){
						//Whenever the animation is NO_ANIMATION, the valve switches to sleep mode
						if(getLEDAnimation() == NO_ANIMATION){
							changePITInterval();
							sleepCounter = 0;
							motorStateChanged = 0;
							mState = SLEEP;
							enablePORTBInterrupt();
							//_delay_ms(500);
							enablePITInterrupt();
							PORTB_OUTCLR = (1<<BLUE_LED);
							sleep_mode();
						}
					
					}
				}
			}else{
			//valve error occured
				if (mState == ACTIVE){
					//Show the errors
					pressType buttonPress = NONE;
					
					if(buttonSensingOn){
						buttonPress = senseMagneticSwitch();
					}
					state_change changeOfState = changeUIState(buttonPress);

					state_change timeOutStateChange = countUITimeOut();
					if(timeOutStateChange != NO_CHANGE){changeOfState = timeOutStateChange;}
					

					_delay_ms(MAINLOOP_DELAY);

					changeLEDAnimation(changeOfState);


					if(getLEDAnimation() == NO_ANIMATION){
						sleepCounter = 0;
						mState = SLEEP;
						PORTB_OUTCLR = (1<<BLUE_LED);
						enablePITInterrupt();
						sleep_mode();
					}



				}else if(mState == PERIODICWAKEUP){
					PORTA.OUTSET = (1<<PIN_REDLED);
					_delay_ms(MAINLOOP_DELAY);
					PORTA.OUTCLR = (1<<PIN_REDLED);

					sleepCounter = 0;
					mState = SLEEP;
					PORTB_OUTCLR = (1<<BLUE_LED);
					enablePORTBInterrupt();
					sleep_mode();
				}
			}
		}else if(mState == SLEEP){
			//Valve does not wake up, but shows warnings
			if(warningState == WARNING){
				if(getValveState() == CLOSED){
					PORTA.OUTSET = (1<<PIN_REDLED);
					PORTB.OUTSET = (1<<PIN_GREENLED);
					_delay_ms(MAINLOOP_DELAY);
					PORTA.OUTCLR = (1<<PIN_REDLED);
					PORTB.OUTCLR = (1<<PIN_GREENLED);
				}
			}
			
				
			sleep_mode();
		}else if(mState == OFF){
			
			if((PORTB_IN & (1<<PIN_MAGNETSWITCH))!=0){	//As long as the button is pressed
				
				pressType button_press = senseMagneticSwitch();
				

				if(button_press == VERYLONG){
					
					mState = ACTIVE;
					changeUIState(SHORT);
					changeLEDAnimation(UI_STARTUP);
				}
				_delay_ms(MAINLOOP_DELAY);
			}else{
				senseMagneticSwitch();	//Call one more time to reset the time counting variables
				sleep_mode();
			}
		}
		
	}
}

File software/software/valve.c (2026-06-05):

/*
 * valve.c
 *
 * Created: 30.11.2022 13:51:29
 *  Author: SteinerF
 */ 

#define F_CPU 3333333
#include <avr/io.h>
#include <util/delay.h>
#include <avr/interrupt.h>


#include "valve.h"
#include "ADC.h"
#include "LEDs.h"

#define PA5_INTERRUPT PORTA.INTFLAGS & PIN5_bm
#define PA5_CLEAR_INTERRUPT_FLAG PORTA.INTFLAGS &= PIN5_bm



volatile valveState motState = OPEN;
volatile valveError error = NO_ERROR;

#define DI_DT_THRESHOLD     1		// Raw ADC difference threshold 
#define TRIGGER_COUNT_MAX   4		//// Number of consecutive spikes needed to stop

uint16_t voltageADC;
uint16_t currentADC;
uint16_t previousADC = 0;
int16_t deltaCurrent;
uint8_t trigger_count = 0;

volatile float calc_volt = 5.0;
uint16_t timeCounter = 0;
uint8_t driveVoltageLowCount = 0;


void initializeValve(){
	
	PORTB_DIRSET = (1<<PIN_MOTORPLUS);
	PORTA_DIRSET = (1<<PIN_MOTORMINUS);
	
	PORTA.DIR &= ~ PIN5_bm;												//Set as input
	PORTA.PIN5CTRL |= PORT_ISC_RISING_gc;			// enable interrupt on rising edge
	
	_delay_ms(100);														//Let the pull-up take effect


	if((PORTA_IN & (1<<PIN_MOTORSTOP))!=0){
		motState = CLOSED;
	}else{
		//PORTB_OUTSET = (1<<BLUE_LED);
	}

	
}

void stopMotor(){
	//Break for 1 second
	PORTA_OUTSET = (1<<PIN_MOTORMINUS);
	PORTB_OUTSET = (1<<PIN_MOTORPLUS);
	_delay_ms(100);
	//Turn off
	PORTB_OUTCLR = (1<<PIN_MOTORPLUS);
	PORTA_OUTCLR = (1<<PIN_MOTORMINUS);
}


void delay_us_precise(uint8_t us) {
	while (us--) {
		_delay_us(1);  // May not be cycle-perfect, but close enough for SW PWM
	}
}

void software_pwm_motorPlus(uint8_t high_time, uint8_t low_time) {


	PORTB_OUTSET = (1<<PIN_MOTORPLUS);
	delay_us_precise(high_time);

	PORTB_OUTCLR = (1<<PIN_MOTORPLUS);
	delay_us_precise(low_time);
}

void software_pwm_motorMinus(uint16_t high_time, uint16_t low_time) {


	PORTA_OUTSET = (1<<PIN_MOTORMINUS);
	delay_us_precise(high_time);

	PORTA_OUTCLR = (1<<PIN_MOTORMINUS);
	delay_us_precise(low_time);
}



valveError openValveAttempt(){
	if((motState == CLOSED || motState == UNDEFINED) && error == NO_ERROR){
		
		voltageADC = ADC_0_readBatteryVoltage();
		
		if(voltageADC <= MIN_VOLT_BEFORE_DRIVE_ADC && motState == CLOSED){
			//error = LOW_VOLTAGE;
			//PORTB_OUTSET = (1<<BLUE_LED);
			return LOW_VOLTAGE;
		}

		PORTA_OUTSET = (1<<PIN_SOILSENSORON);

		valveError intermediateError = NO_ERROR;
		

		//clearBuffer(&rb);
		prepareReadingCurrent(SAMPLE_ACCUM_OPEN, ADC_PRESC_DIV16_gc);

		timeCounter = 0;
		trigger_count = 0;

		uint16_t filteredCurrent = 512;  // Initialize with a high value to start filtering
		uint8_t enoughSamples = 0;
		uint8_t sampleCounter = 0;

		motState = OPENING;
		//PORTA_OUTSET = (1<<PIN_MOTORMINUS); // set HIGH;
		//_delay_ms(300);

		for (uint8_t duty = 20; duty <= 40; duty++) {
			for (uint8_t i = 0; i < 120 ; i++) {
				software_pwm_motorMinus(duty, 40-duty);
			}
		}

		PORTA_OUTSET = (1<<PIN_MOTORMINUS);
		
		_delay_ms(200);




		//With a prescaler of 16 and a sample accumulator of 64 the loop time is pretty much exactly 4ms, in that time the motor shaft rotates 0.24 degrees at 10RPM
		while(motState == OPENING && timeCounter <= OPEN_TIMEOUT){

			currentADC = ADC_0_readCurrent(SAMPLE_ACCUM_OPEN);

			// Apply lightweight IIR filter
			filteredCurrent = (3 * filteredCurrent + currentADC) / 4;
			//filteredCurrent = newSample;

			// Approximate dI/dt as difference per call (assuming fixed time step)
			deltaCurrent = filteredCurrent - previousADC;
			previousADC = filteredCurrent;

			if(enoughSamples == 0){
				sampleCounter++;
				if(sampleCounter >= 4){
					enoughSamples = 1;
				}
			}
			
			if(enoughSamples){
				// Detect sharp rise
				if (deltaCurrent > DI_DT_THRESHOLD) {
					trigger_count++;
				} else {
					trigger_count = 0;  // Reset on stable current
				}

				if (trigger_count >= TRIGGER_COUNT_MAX || filteredCurrent >= OPEN_CURRENT_LIMIT_ADC) {
					
					//PORTA_OUTCLR = (1<<PIN_MOTORMINUS);
					//_delay_ms(100);
					stopMotor();
					//Carefully open a little
					for (uint8_t duty = 20; duty <= 40; duty++) {
						for (uint8_t i = 0; i < 120 ; i++) {
							software_pwm_motorPlus(duty, 40-duty);
						}
					}
					motState = OPEN;
					break;
				}
			}
			

			
			/*
			if(currentADC > OPEN_CURRENT_LIMIT_ADC){

				//PORTA_OUTCLR = (1<<PIN_MOTORMINUS);
				//_delay_ms(100);
				stopMotor();
				//Carefully open a little
				for (uint8_t duty = 20; duty <= 40; duty++) {
					for (uint8_t i = 0; i < 120 ; i++) {
						software_pwm_motorPlus(duty, 40-duty);
					}
				}

				motState = OPEN;
				break;
			}
			*/
			
			timeCounter++;
			

		}

		stopMotor();
		
		//PORTA_OUTCLR = (1<<PIN_MOTORMINUS);
		motState = OPEN;
		

		if(timeCounter>=OPEN_TIMEOUT){
			
			intermediateError = VALVE_TIMEOUT;
			//PORTA_OUTSET = (1<<PIN_REDLED);
		}
		
		//PORTB_OUTSET = (1<<BLUE_LED);
		//IGNORE ERROR STATES FOR DEV
		//error = NO_ERROR;
		PORTA_OUTCLR = (1<<PIN_SOILSENSORON);	//Turn off motor driver
		_delay_ms(100);			//Let the motor calm down before driving it in the other direction

		return intermediateError;
	}

	return NO_ERROR;
	
}
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

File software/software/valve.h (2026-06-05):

/*
 * valve.h
 *
 * Created: 02.11.2022 16:19:30
 *  Author: SteinerF
 *
 *	Interface to the motor for opening and closing the valve
 *  Peripherals needed: Button Interrupt, ADC
 */ 


#ifndef VALVE_H_
#define VALVE_H_

#define OPEN_CURRENT 0.45
#define CLOSE_CURRENT 0.80 //prod
//#define CLOSE_CURRENT 0.40 //test
//#define SAMPLE_ACCUM ADC_SAMPNUM_ACC16_gc

#define SAMPLE_ACCUM_OPEN ADC_SAMPNUM_ACC64_gc
#define SAMPLE_ACCUM_CLOSE ADC_SAMPNUM_ACC64_gc


#define OPEN_TIMEOUT 1000		//Prod
//#define OPEN_TIMEOUT 90		//Test
#define CLOSE_TIMEOUT 1000		//Prod
//#define CLOSE_TIMEOUT 200		//Test

#define PIN_MOTORPLUS 1		//PORTB
#define PIN_MOTORMINUS 6	//PORTA
#define PIN_MOTORSTOP 5		//PORTA

#define MAX_VOL 9.9
#define MIN_VOL_DRIVE 4.0
#define MIN_VOL_DRIVE_BEFORE_WARNING 4.3
#define MIN_VOL_BEFORE_DRIVE 7.0	//Prod
//#define MIN_VOL_BEFORE_DRIVE 4.0	//Testing
#define MAX_CUR 1.0			//Bei 0.2 Ohm Shunt

#define DRIVE_VOLTAGE_LOW_TRIGGER 5

#define OPEN_CURRENT_LIMIT_ADC (uint16_t)(RES_10BIT / MAX_CUR * OPEN_CURRENT)
#define CLOSE_CURRENT_LIMIT_ADC (uint16_t)(RES_10BIT / MAX_CUR * CLOSE_CURRENT)
#define MIN_VOLT_DRIVE_ADC (uint16_t)(RES_10BIT / MAX_VOL * MIN_VOL_DRIVE)
#define MIN_VOLT_DRIVE_BEFORE_WARNING_ADC (uint16_t)(RES_10BIT / MAX_VOL * MIN_VOL_DRIVE_BEFORE_WARNING)
#define MIN_VOLT_BEFORE_DRIVE_ADC (uint16_t)(RES_10BIT / MAX_VOL * MIN_VOL_BEFORE_DRIVE)

typedef enum {UNDEFINED=1, OPEN=2, CLOSED=5, OPENING = 20, CLOSING = 40}  valveState;
typedef enum {WRONG_SENSOR_PLACEMENT = 1, LOW_VOLTAGE=2 , HIGH_CURRENT=3, VALVE_TIMEOUT=4, NO_ERROR}  valveError;

/*
Errors Meanings
	WRONG_SENSOR_PLACEMENT: When Valve is open for longer then 2 hours, it is assumed that either the sensor is placed wrong or there is something wrong with the water source or pipes/hoses - this is the only error that can be resolves by just pressing the button
	VOLTAGELOW:		When Voltage got too low (<4V when driving, <7V before driving). Usually Valve ends up in a safe closed position
	HIGH_CURRENT:	When Current got too high when closing (the motor could potentially damage itself without this). Causes: End Stop Button is damaged or out of physical Range (Housing Deformation) OR motor gears are broken OR problems with motor brushes or coils. Valve might end up in an open or partly open position.
	VALVE_TIMEOUT:	When the Motor was driving a certain time and the valve is still not closed. Causes: Damaged Motor Gears, solder error on PCB, disconnected cables to the motor, malfunctioning motor driver IC, motor driver IC in sleep mode. Also occurs while assembling when motor shaft must be turned in a suitable position to attach the valve parts. Valve is probably in an open or partly open position.
*/

//Figure out state of valve, if not closed, close it
void initializeValve();

void openValve();

void closeValve();

void changeMotorState();

valveState getValveState();

valveError getValveError();
void setValveError(valveError err);

void motorPositioningMode();

uint8_t getDriveVoltageLowCount();



#endif /* VALVE_H_ */

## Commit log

2022-10-16 Added working Microchip Studio Project with blinky + UART output
2022-12-01 Added Functionality: Valve open, Valve close; Added functionality: Read Soil Moisture Sensor
2023-01-06 Basic functionality established: Valve opens when ADC Reading from soil moisture sensor above 512 and closes when its below
2023-01-22 Make LED glow when Magnet sensor is on
2023-02-17 Small modifications of values in valve opening/closing, Added Interfaces for UI
2023-02-19 Added LED animations
2023-02-26 Added User Interface and Battery Sensing
2023-05-21 Fixed bug: Program got stuck in while loop when ADC was occupied and never released, other small improvements
    [ADC.c, main.c, valve.c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]
2023-09-09 Added pcb
2023-10-27 Restructured Software, Added Support for Blue LED
2024-02-11 Significantly improved valve control code to detect drained battery and other possible errors like broken hardware
    [ADC.c, ADC.h, main.c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]
2024-02-26 Added turning valve on and off, added software version animation, improved other animations
2024-03-03 Error States (different fail saves) are displayed now - User can look up which error occured
    [LEDs.c, LEDs.h, UserInterface.c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]
2024-03-18 Changed some parameters regarding valve opening/closing
2024-06-17 Motor code polishing, Added p-channel to pcb for reverse voltage protection
    [ADC.c, ADC.h, valve.c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]
2024-06-30 Fixed bug: Freeze at startup, small UI corrections: Faster recognition of long button presses, Corrected Version, instead of blink steady glow when slecting settings
    [ADC.c, ADC.h, LEDs.c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]
2024-07-30 Added Correct Sensor interpretation for SoilWatch 10
    [ADC.c, UserInterface.c, valve.c]
2024-08-02 Fixed wrong ADC voltage reference for soil moisture sensor, started logic for supporting different soild moisture sensors, standby led now blinks in standby mode when valve is open instead of glowing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
    [ADC.c, ADC.h, SoilMoistureSensor.h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]
2025-04-08 New PCB Version 0.1
2025-04-19 Changed Software to work with new Pull down Resistors and new Motor driver
2025-05-21 Motor PWM Rampup for lower voltage drop; Valve doesnt open if battery is below 7V; Multiple Closing attempts before entering HIGH CURRENT error; Introduced new valveState: WRONG_SENSOR_PLACEMENT -> a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
    [ADC.c, ADC.h, LEDs.c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]
2025-05-25 Made blink count animations slightly slower; Fixed bug where showing current soil moisture animation was behaving wrong because the value got updated mid animation
    [LEDs.c, valve.h]
2025-07-27 Improved valve opening logic
2026-01-31 Added an assembly state where each button drives the motor slowly in on or another direction. This change makes the assembly process significantly easier and safer
2026-02-16 Added READMEs and documentation, Added KiCad Project, Added 3D Files
    [0ZCG0075FF2C.STEP, BatteryLid.3mf, Button.stl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]
2026-05-07 Changed Housing_Down to support the hydrophobic vent
    [Housing_Down.stl]
2026-06-03 Fixed bug where current soil moisture did not perfectly cohere with the opening threshold value
    [ADC.c, SoilMoistureSensor.h, UserInterface.c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]
2026-06-03 OpenValve now flashes orange LED occasionaly when closed and sleeping as a warning for low battery
2026-06-04 Introduced warning for when silicone sleeve is worn and should be changed (when valve cycles > 1450, + possiblity to reset valve cycle counter after changing the sleeve
    [ADC.h, LEDs.c, LEDs.h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]
2026-06-04 Improved Battery Indication: 4 instead of 3 indications: new indication level shows specifically when its time to change the battery, Improved Battery Low detection
2026-06-05 Slightly improved failsafe behaviour
    [valve.c, valve.h]
2026-06-23 changed 3d-models and description, adjustable slider added.
    [Guide.stl, Housing_Down.stl, Housing_Up.stl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]
2026-06-24 Changed startup LED sequence to only show software version, changed standard opening threshold to 1, changed software version to 1.2, changed timeout to be almost exactly after 60 seconds
2026-06-24 Warning blinks halfed in duration to reduce battery drainage when warning is active
2026-06-26 Fixed edgecase bugs that are very unlikely to occur: motor error when switching the valve into off-state is now handled better by being shown immediately, corrupted epprom changes fixed: when initial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
    [LEDs.c, UserInterface.c, main.c]
2026-07-01 Updated Readme, moved alternative applications and examples to different location, Updated Construction markdown
    [continuousHoseFitting.stl]
2026-07-09 Changed pressure spec, applications further up in readme
2026-07-14 Added link to purchase assembly kit, removed availability section
2026-07-22 Added PCB Design File, OpenValve is now fully open source
    [PG_attiny404.kicad_pcb, PG_attiny404.kicad_sch]
2026-07-22 Added complete BOM for OpenValve and the self-sourcing option in Construction.md
2026-08-06 Added OpenValve Assembly in .STEP format, small corrections in documentation
2026-11-07 Added Support for SMT50 soil moisture sensor
